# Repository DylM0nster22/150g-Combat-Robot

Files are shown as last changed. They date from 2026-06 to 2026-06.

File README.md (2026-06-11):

# 150g Combat Robot

This is a 150g combat robot that I made that uses the gyroscopic forces of its weapon to move. This is a cool robot because instead of using wheels to move around, it uses bristles and an unbalanced weapon to create vibrations to get controlled movement,
kinda like a hex bug would. I made this because I have multiple combat robots, but I don't have a single good fairyweight bot, so for my first good fairy, I decided to make something that could be super powerful. This robot should be one of the hardest-hitting fairies if it works, because just the weapons alone weigh 2/3 of a normal fairy. For this bot, the wiring is super simple. The diagram I made is really bad, but this is how it goes. The positive goes to one side of the power switch, and the other side of the power switch goes to the ESC and receiver. The ground also goes to the receiver and esc. The three phase wires from the motor go to any of the three pads on the ESC. The signal wire from the ESC goes to channel 3 on the receiver.


Here's how the robot looks

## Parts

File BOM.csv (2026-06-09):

Part | Weight | Cost | Quantity | Spare quantity | Total Cost + shipping | Total Weight | link
Weapon | 42.6 |  | 2 | 1 | 17.52 | 85.2 | sendcutsend
Weapon hub | 5.02 |  | 1 | 1 |  | 5.02
Drive motor hub | 2.83 |  | 1 | 1 |  | 2.83
Weapon motor | 21.1 | 28.5 | 1 | 1 | 26.74 | 21.1 | https://www.aliexpress.us/item/3256806491510449.html
Weapon ESC | 3.5 | 5.05 | 1 | 1 | 10.84 | 3.5 | https://www.aliexpress.us/item/3256808919105106.html | Normal version
Battery | 19 | 26.99 | 1 | 0 | 28.95 | 19 | https://www.amazon.com/OVONIC-300mAh-Battery-Voltage-Package/dp/B0D2L17M8H
Reciever | 1 | 4.86 | 1 | 0 | 7.15 | 1 | https://www.aliexpress.us/item/3256805805961445.html?gatewayAdapt=glo2usa
Power Switch | 2.2 | 9 | 1 | 0 | 14 | 2.2 | https://repeat-robotics.com/collections/antweight/products/fingertech-switch
Belt | 1.5 | 3.64 | 1 | 1 | 9.18 | 1.5 | https://www.aliexpress.us/item/3256806630919356.html?curPageLogUid=jU0sqGyD0j2h | 2GT-252 4mm width
Trusses | 24.5 |  | 1 | 1 | 22.76 | 24.5 | sendcutsend
Body | 18 |  | 1 | 2 | 13.61 | 18 | https://www.amazon.com/DMiotech-Molecular-Polyethylene-Automotive-Manufacturing/dp/B0D79CQFLM
Standoff | 0.72 |  | 4 | 0 | 5.01 | 2.8 | https://www.aliexpress.us/item/3256802989279920.html?curPageLogUid=P0pePeHZMBDg | m3x18
weapon shaft | 4 |  | 1 | 0 | 9 | 4 | https://www.amazon.com/MECCANIXITY-Stainless-Hydraulic-Injection-Industries/dp/B0FDQ9YN9R?s=industrial
Top lid | 5 | 19.25 | 2 | 0 | 18.58 | 10 | https://www.amazon.com/TEGRIS-Thermoplastic-Composite-Sheet-Resistant/dp/B0DH9GFW36
Thrust washer | 2.7 | 7.93 | 2 | 0 | 7.93 | 5.4 | https://www.amazon.com/uxcell-Bearings-Diameter-Thickness-Steering/dp/B0DQ8T13KV?s=industrial
Bearing | 1.6 | 1.94 | 2 | 1 | 8.23 | 3.2 | https://www.aliexpress.us/item/3256809216252166.html?mp=1 | HK0406(4x8x6) 1pc
Brisltes | 1 |  | 4 | 0 |  | 4
 |  |  |  |  |  | -213.25
 |  |  |  |  |  | 225
 |  |  |  | Total price = | 199.5 | 11.75

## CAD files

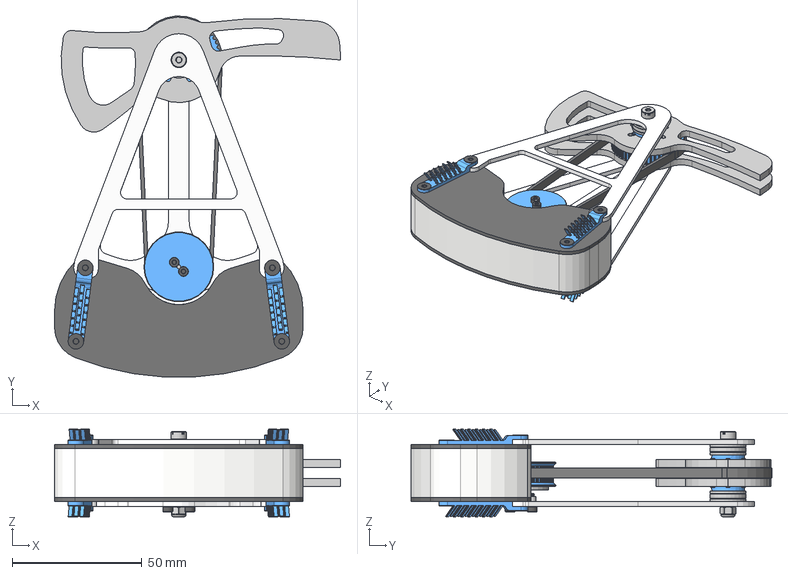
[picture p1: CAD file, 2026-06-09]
CAD/Bot.step
110.4 x 139.3 x 33.9 mm
gears v1
motor
Top lids
Chassis
trusses
Battery
5909K1_Needle-Roller Thrust Bearing x 2
5909K291_1 mm Thick Washer for 4 mm Shaft Diameter Needle-Roller Thru st Bearing x 4
90269A211_316 Stainless Steel Shoulder Screw
91294A128_Black-Oxide Alloy Steel Hex Drive Flat Head Screw x 2
91294A128_Black-Oxide Alloy Steel Hex Drive Flat Head Screw_1 x 2
91294A128_Black-Oxide Alloy Steel Hex Drive Flat Head Screw_2 x 2
91294A128_Black-Oxide Alloy Steel Hex Drive Flat Head Screw_3 x 2
91290A012_Black-Oxide Alloy Steel Socket Head Screw
90453A111_Thin-Profile Nylon-Insert Locknut

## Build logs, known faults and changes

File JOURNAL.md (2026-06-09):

## 6/6/26 - Making the weapon

So far today, I have made the initial weapon design. For this weapon, I started by trying to make a basic asymmetrical weapon, but it just didn't look good to me, so then I tried to make a more axe-ish shaped weapon, but no matter what I did, I just couldn't get it to look right, so I restarted again. That's how I ended up with the newest design. The total weapon diameter is around 5 inches and will weigh about 48 grams per weapon, which is over half of the weight of a normal fairy, but bristle bots get weight bonuses of 1.5x, so I'm chilling, I think… here's how the weapon looks


I spent an hour and 46 minutes on this, according to Hakatime


## 6/8/26

This is going to be a long one. Over the last two days, I finished the whole robot. idk why, but yesterday I just forgot to journal at all, and I just wanted to lock in on the cad today instead of journaling. For this long journal, I'm going to use Fusion's timeline to go back and forth. I started the bot by making a flat body and the beginning of the truss that connected the weapon to the body. 

Once I finished that, I made the initial body shape, which had a rounded back, holes for the standoffs to go in, and fairly thick walls because it was going to be printed out of TPU.



After that, I made the whole chassis a little bit thinner to try to save on weight and optimize the design, and made the top truss, which consisted of mirroring the bottom up to the top and editing it to be lighter.



Then I had an idea to make the bot way stronger. I could make the body solid UHMW. Doing this makes it better because then I wouldn't have to worry about layer lines being a failure point, and UHMW is lighter than TPU while being tougher overall. To account for it being solid, I thinned the walls out to about 3mm thick. I then added a top lid, which is going to be made of 1.5mm tegris, and I filled out all the holes on the truss.



By this point, I still didn't have a weapon hub or any real optimization because I didn't even start weight calcs, and because this was a fairy, I thought I was only going to be able to run 1 weapon. Once I started the weight calcs, I realized if I switched to a slightly smaller motor, I might have a chance to run two steel weapons in the fairy weight class, which is unheard of. So I switched the motor out to a BetaFPV 2006 motor, which should still have plenty of torque. And I also decided to switch the battery from 3s to 2s to save weight. After I decided to change the weapon motor out I started making the pullies and once I made those I put them in the slicer to get a inital weight and I relized that that the weapons weighed way to much like each weighed 48g which is a third of the weight of a normal fairy and I had two of them... so I downsized the center of the weapon to use m2 screws instead of m3 screws but because im using so many of them it should have any issues with shearing. By this point, I had thinned the truss's thickness from 3.2mm to 2.5mm to save more weight. I also thinned out the whole robot even more because with a smaller motor, I had more wiggle room. Heres how it looked.



At this point, I decided to pocket the weapon even more and make the hub slightly smaller again to save on more weight. Once I redid the weight calcs, I realized I was still going to be overweight, so I made the body smaller again, this time by bringing in the back of the bot, which is going to make wiring tighter, but I should still have plenty of room. After that, I started adding all my hardware and actually making the pulleys I would use. Thankfully, I found a tool in Fusion to make the GT2 pulleys easily. For this bot, I'm using two different types of bearings to make it super smooth: needle roller bearings inside the weapon hub and thrust washers on the outside to keep it centered. After I got everything aligned, I pocketed the weapon even more, which ended up getting the weight per weapon down to 43g, which is still absurd. The weapons at this point are bigger than the rest of the bot, by a lot, so there might be a chance the body just spins around the weapons, but we'll see. After that, I made the actual bristles, which are angled little rectangles that connect to the screw holes that hold the trusses and top lids onto the bot. These are what allow the movement of the bot. And that's it, that's somehow 9 hours of work, well, it's actually more than that because I had to work on the BOM. Overall, the bot's materials are AR500 for the weapon, UHMW for the body, TPU for the weapon hub, pullies, and bristles, and aluminium for the truss. According to my weight calcs I should have about 11 grams for screws and wires. Here's how the bot looks now with all the screws 



I spent 9 hours and 26 minutes according to Hackatime



## Total Time Spent on Cad: 11 hours and 16 minutes.
## Total Time Spent: 12.5 hours
